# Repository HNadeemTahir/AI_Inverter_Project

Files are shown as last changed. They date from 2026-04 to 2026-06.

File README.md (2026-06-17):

# Solar Inverter & MPPT Booster — Simulation to Hardware

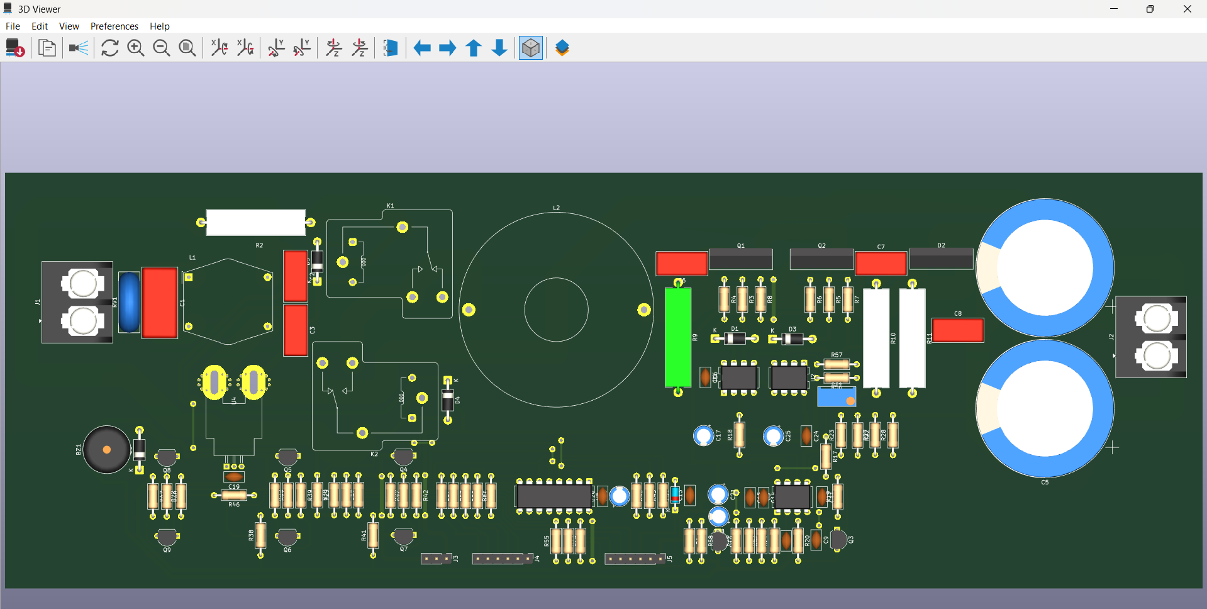
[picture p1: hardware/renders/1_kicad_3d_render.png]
4kW MPPT Booster PCB — KiCad 3D Render


NgSpice simulation and KiCad PCB design of a complete off-grid solar power system. The simulation uses manufacturer SPICE models (not ideal switches) and translates dsPIC30F2010 firmware logic into behavioral equations so the control loops can be validated before building hardware.

Two power conversion stages, developed across 10 versions:

1. **H-Bridge Inverter** — Single-phase 220V/50Hz pure sine wave output using FGY75T120SWD IGBTs, unipolar SPWM, closed-loop PI voltage regulation, electro-thermal monitoring, and hardware fault protection.
2. **4kW MPPT Boost Converter** — DC-DC front-end regulating a variable 120V–350V PV string to a stable 380V DC bus, controlled by a UC3843 analog controller slaved to a dsPIC30F2010 MCU.

---

## Note on Methodology

The workflow here — simulate with real device models, sweep parameters with Python, train a surrogate model, then route the PCB — is not specific to boost converters. The same approach works for any power stage where you need to predict switching losses and thermal behavior before committing to hardware. I have used variations of this on inverter gate drives, motor current loops, and industrial servo tuning.

---

## Project Phases at a Glance

| Version  | Focus Area | Key Achievement |
|:---:|:---|:---|
| V1.0 | Environment Setup | NgSpice + library structure established |
| V2.0 | Half-Bridge SPWM | Ideal switching, basic sine generation |
| V3.0 | Physical IGBT Models | Real FGY75T120SWD switching behavior |
| V4.0 | Full H-Bridge + LC | Unipolar SPWM, motor load, phase lag verified |
| V5.0 | Closed-Loop PI Control | ZMPT101B sensor delay, voltage regulation |
| V6.1 | Dead-Time + Thermal | 2µs shoot-through protection, Foster RC model |
| V6.3 | Python Automation | Batch simulation, CSV data extraction |
| V6.5 | Modulation Benchmark | THI + Dead-Time compensation matrix |
| V7.0 | Surrogate Model | Scikit-Learn Random Forest predictor |
| V8.0 | 4kW MPPT Converter | Feed-forward + PI boost, 3 test profiles |
| V9.0 | UC3843 Control Loop | Analog-digital MPPT integration, gate physics |
| **V10.0**| **Hardware PCB** | **KiCad layout, DRC-clean, 3D-verified** |

---

## Hardware Implementation (KiCad)

The 4kW MPPT booster control board, designed in KiCad 9.0. DRC-clean. The schematic and layout match the UC3843 + dsPIC control architecture from V8.0 and V9.0 simulations.

### PCB 3D Render — Component Side
PCB Top View

### PCB 3D Render — Isometric View
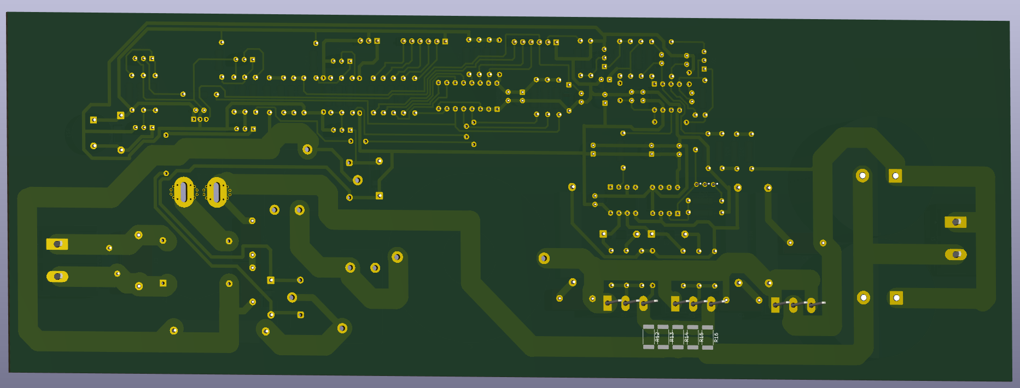
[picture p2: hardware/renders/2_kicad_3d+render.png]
PCB Isometric


### Hardware Design Files

| File | Description |
|:-----|:---|
| [`MPPT_Booster_4kW_Hardware.kicad_pro`](hardware/kicad/MPPT_Booster_4kW_Hardware.kicad_pro) | KiCad 9.0 project file |
| [`MPPT_Booster_4kW_Hardware.kicad_sch`](hardware/kicad/MPPT_Booster_4kW_Hardware.kicad_sch) | Full schematic (UC3843 + dsPIC + gate drivers + current sensing) |
| [`MPPT_Booster_4kW_Hardware.kicad_pcb`](hardware/kicad/MPPT_Booster_4kW_Hardware.kicad_pcb) | PCB layout with copper pours, clearance rules, and thermal relief |
| [`DRC.rpt`](hardware/kicad/DRC.rpt) | Design Rule Check report |

### Key Layout Decisions

- **High-current paths** (inductor → IGBT → diode → output caps) use wide copper pours with thermal relief pads to handle 20A+ continuous current
- **Gate driver isolation** — FOD3150 optoisolators provide galvanic separation between the dsPIC logic ground and the power stage ground
- **Current sensing** — INA181A2 shunt amplifier placed directly adjacent to the sense resistor to minimize noise pickup
- **Analog control section** — UC3843, slope compensation network, and RC timing components grouped together with short trace runs

---

## Version 9.0 — UC3843 Analog Control Loop Integration

This version implements the hardware-level control architecture of the 4kW MPPT booster. It moves beyond behavioral SPICE switches into a real analog control loop where a **UC3843 peak-current-mode PWM controller** is directly slaved to the **dsPIC30F2010** MCU via a KCL-balanced voltage summing node.

### Engineering Targets Achieved

| Target | Method | Status |
|:---|:---|:---:|
| Analog-digital MPPT interface | KCL summing node on UC3843 Pin 2 | ✅ Proven  |
| Cold-boot explosion prevention | 10kΩ pull-up on dsPIC OC1 PWM line | ✅ Proven  |
| Precharge relay MCU isolation | 2N2222 NPN driving 40A contactor coil | ✅ Proven  |
| Sub-harmonic oscillation fix | 2N3904 NPN emitter-follower slope compensation | ✅ Proven  |
| 100ns turn-on noise rejection | 1kΩ + 470pF LEB filter on UC3843 Pin 3 | ✅ Proven  |
| IGBT Miller plateau characterization | Asymmetric gate drive: 15Ω ON / 5.6Ω+D OFF | ✅ Proven  |
| dsPIC PWM-to-analog conversion | 10kΩ + 4.7µF RC filter: 3.3Hz cutoff | ✅ Proven  |

### Test 1 — MPPT Summing Node: dsPIC Duty Cycle Sweep
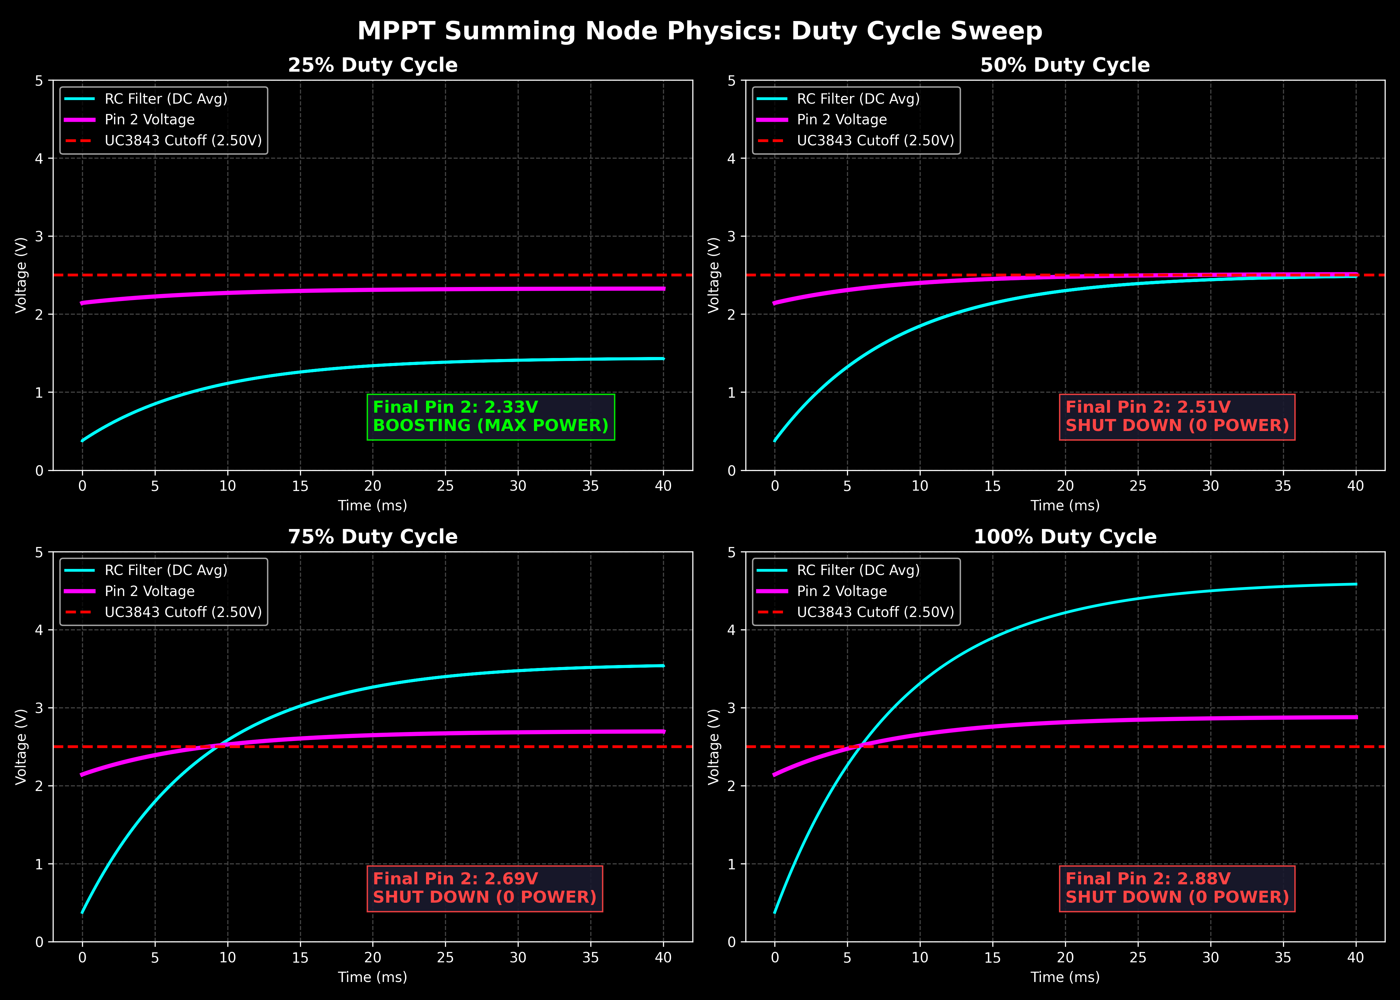
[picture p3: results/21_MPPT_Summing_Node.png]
Summing Node Sweep


Four-point parametric sweep of the dsPIC OC1 PWM duty cycle. Proves the KCL summing node physics: at 25% duty cycle, Pin 2 settles below 2.50V and the UC3843 boosts at maximum power. At 50%–100%, Pin 2 rises above the 2.50V threshold and the converter shuts down in a controlled manner. The 10kΩ pull-up resistor ensures this safe state is the default during MCU boot.

| dsPIC PWM | RC Filter Output | Pin 2 Voltage | UC3843 State |
|:---:|:---:|:---:|:---|
| 25% | 1.25V | 2.33V | Boosting (MAX POWER) |
| 50% | 2.50V | 2.51V | Shut Down |
| 75% | 3.75V | 2.69V | Shut Down |
| 100% | 5.00V | 2.88V | Shut Down |

### Test 2 — Gate Capacitance Charge/Discharge Analysis
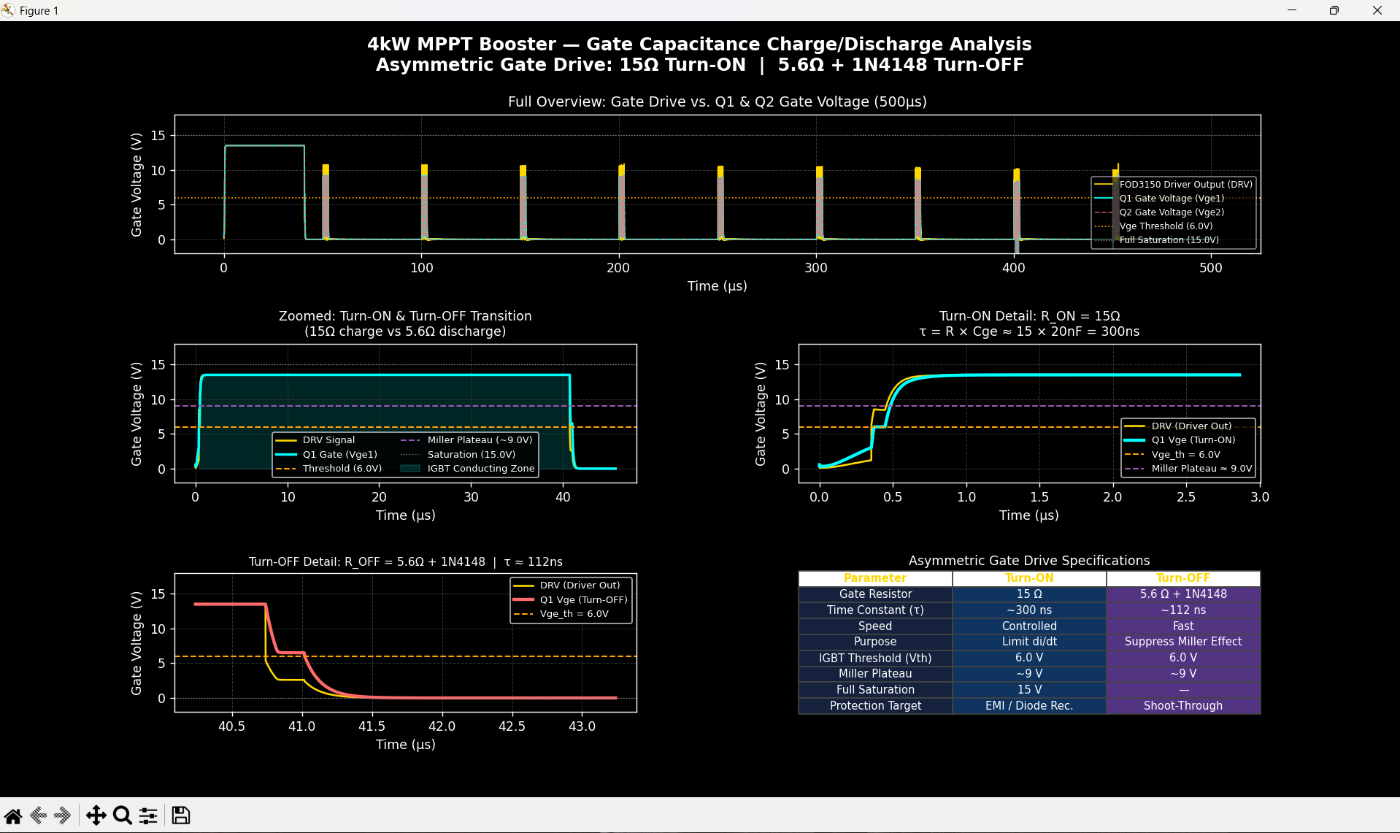
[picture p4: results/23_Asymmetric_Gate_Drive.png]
Gate Analysis Dashboard


500µs high-resolution transient analysis of the asymmetric gate drive network on the STGW60H65DFB parallel IGBT pair. Characterizes the Miller Plateau crossing, threshold voltage events, and the turn-on/turn-off time constants resulting from the 15Ω / 5.6Ω+1N4148 resistor-diode network.

| Parameter | Turn-ON | Turn-OFF |
|:---|:---:|:---:|
| Gate Resistor | 15 Ω | 5.6 Ω + 1N4148 |
| Time Constant (τ) | ~300 ns | ~112 ns |
| Purpose | di/dt limiting, diode recovery ctrl  | Miller effect suppression, shoot-through prevention |
| IGBT Threshold (Vth) | 6.0 V | 6.0 V |
| Miller Plateau | ~9 V | ~9 V |
| Full Saturation | 15 V | — |

### Test 3 — UC3843 Closed-Loop Boost Converter
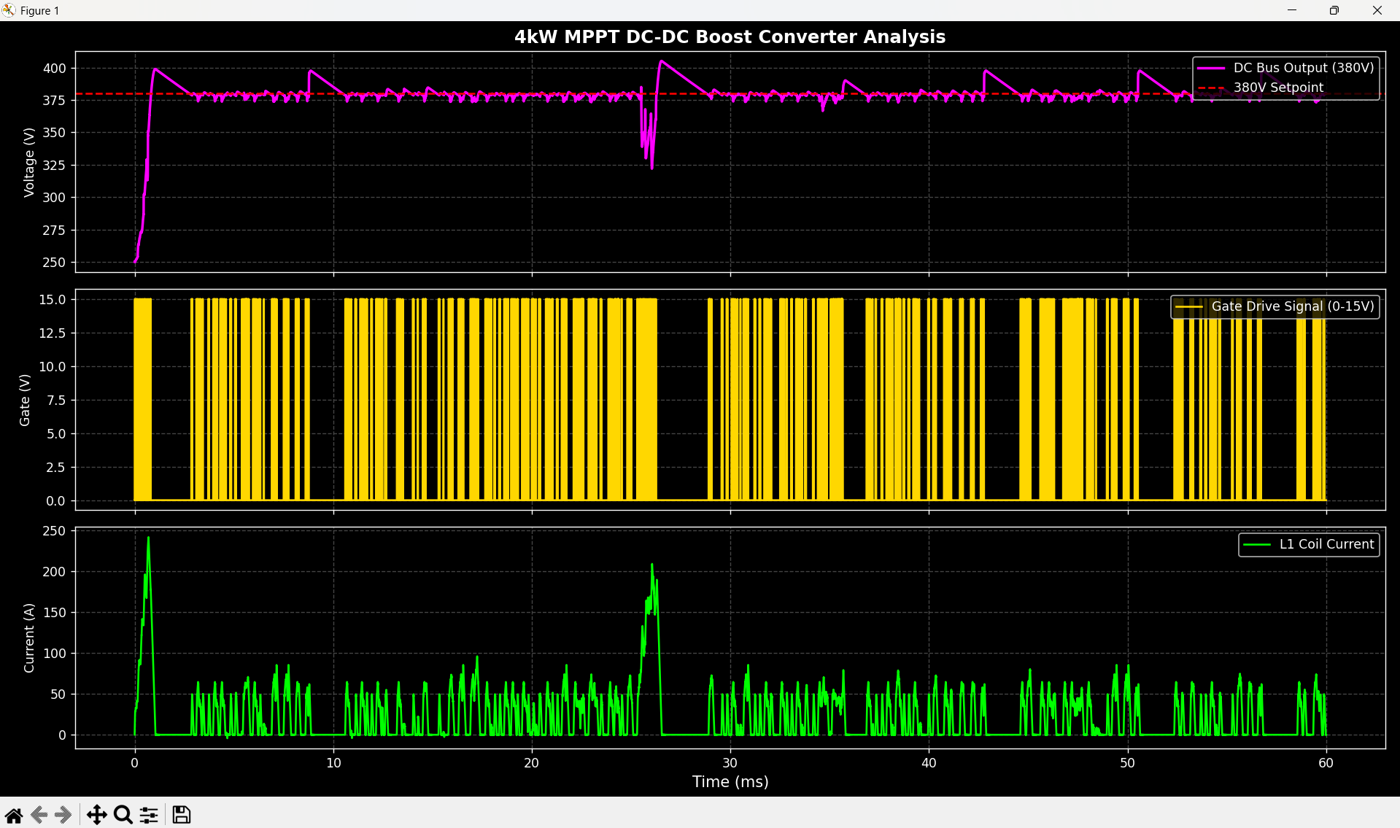
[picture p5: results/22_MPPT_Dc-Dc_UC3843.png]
MPPT UC3843 Dashboard


Full closed-loop simulation of the UC3843 controlling the power stage. Shows the DC bus regulation, inductor current waveform, and the 20kHz gate drive signal across the full 60ms transient window.

### Test 4 — LEB Filter: 470ns Current Sense Propagation Delay
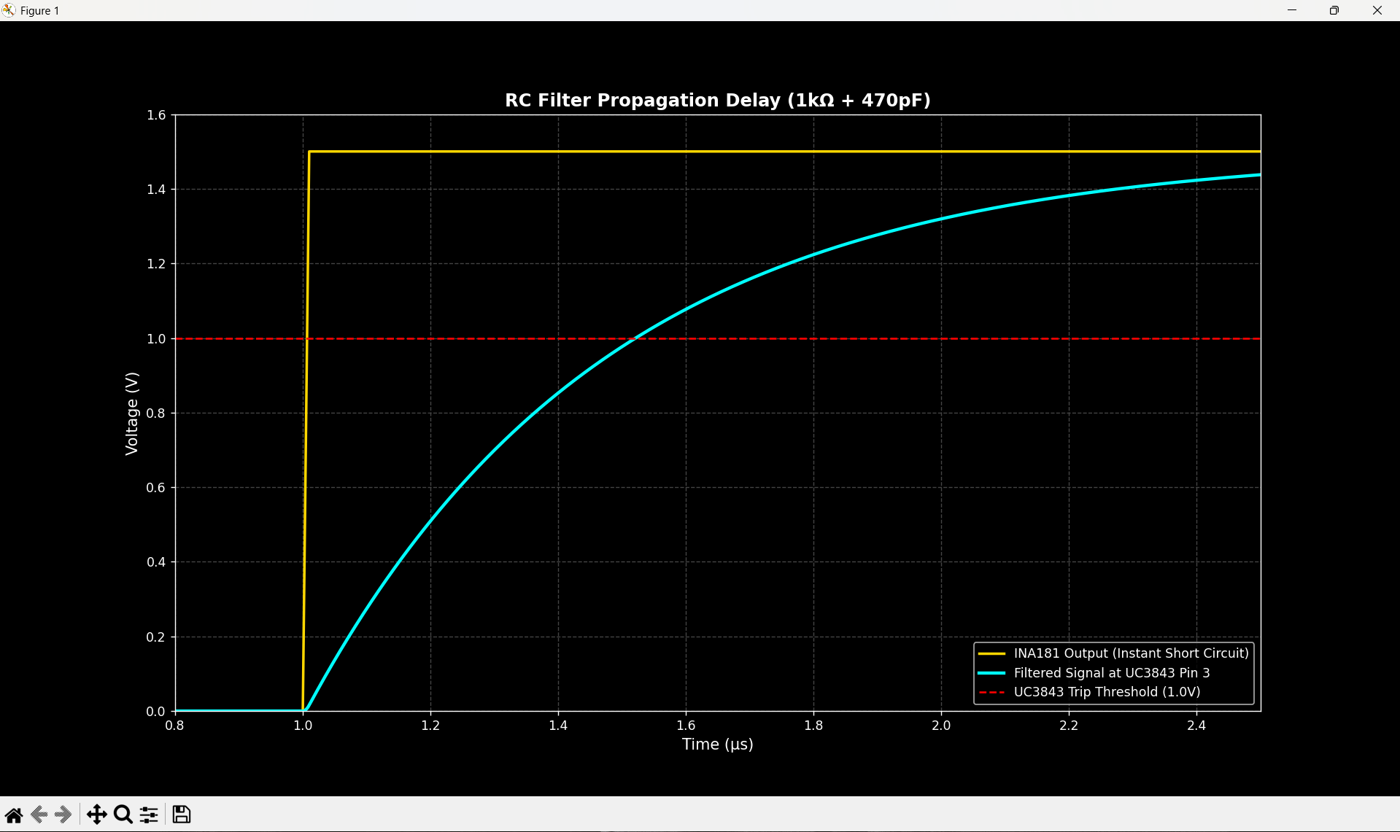
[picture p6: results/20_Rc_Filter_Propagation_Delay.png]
RC Filter Delay


Step-response analysis of the Leading Edge Blanking (LEB) filter at UC3843 Pin 3. A simulated dead-short event causes the INA181 output to jump instantaneously to 1.5V. The 1kΩ + 470pF RC filter delays the signal reaching the 1.0V trip threshold by 470ns — exactly the blanking window required to mask IGBT turn-on current spikes while remaining fast enough to detect a genuine short circuit within one switching cycle.

---

## Version 8.0 — 4kW MPPT Boost Converter

Full power-stage simulation of the 4kW DC-DC booster. Feed-forward + PI control architecture handles 3-panel to 8-panel PV string inputs.

### Booster Specifications

| Parameter | Value |
|:---|:---|
| Input Range | 120V – 350V DC |
| Output | 380V DC (regulated) |
| Max Power | 4000W |
| Switching Frequency | 20kHz |
| IGBTs | 2× STGW60H65DFB (650V/60A, parallel) |
| Boost Diode | STTH3006D (600V/30A, 35ns Trr) |
| Gate Driver | FOD3150 (optically isolated) |
| Control | Feed-Forward + PI with anti-windup |

### Validated Test Profiles

| Profile | Input | Load  | Steady State | Verdict  |
|:---|:-----:|:-----:|:---:|:---:|
| 3-Panel String | 120V  | 1500W | 380V flat | **PASS** |
| 5-Panel String | 250V  | 3000W | 380V flat | **PASS** |
| 8-Panel String | 350V  | 4000W | 380V ±10V† | **PASS** |

† Bounded oscillation at 350V is LC resonance at near-unity boost ratio. Eliminated in firmware by a single-coefficient EMA filter: `vbus_filt = 0.015 * raw + 0.985 * filt`.

### Profile 1: 120V → 380V (1500W, Boost Ratio 3.17×)
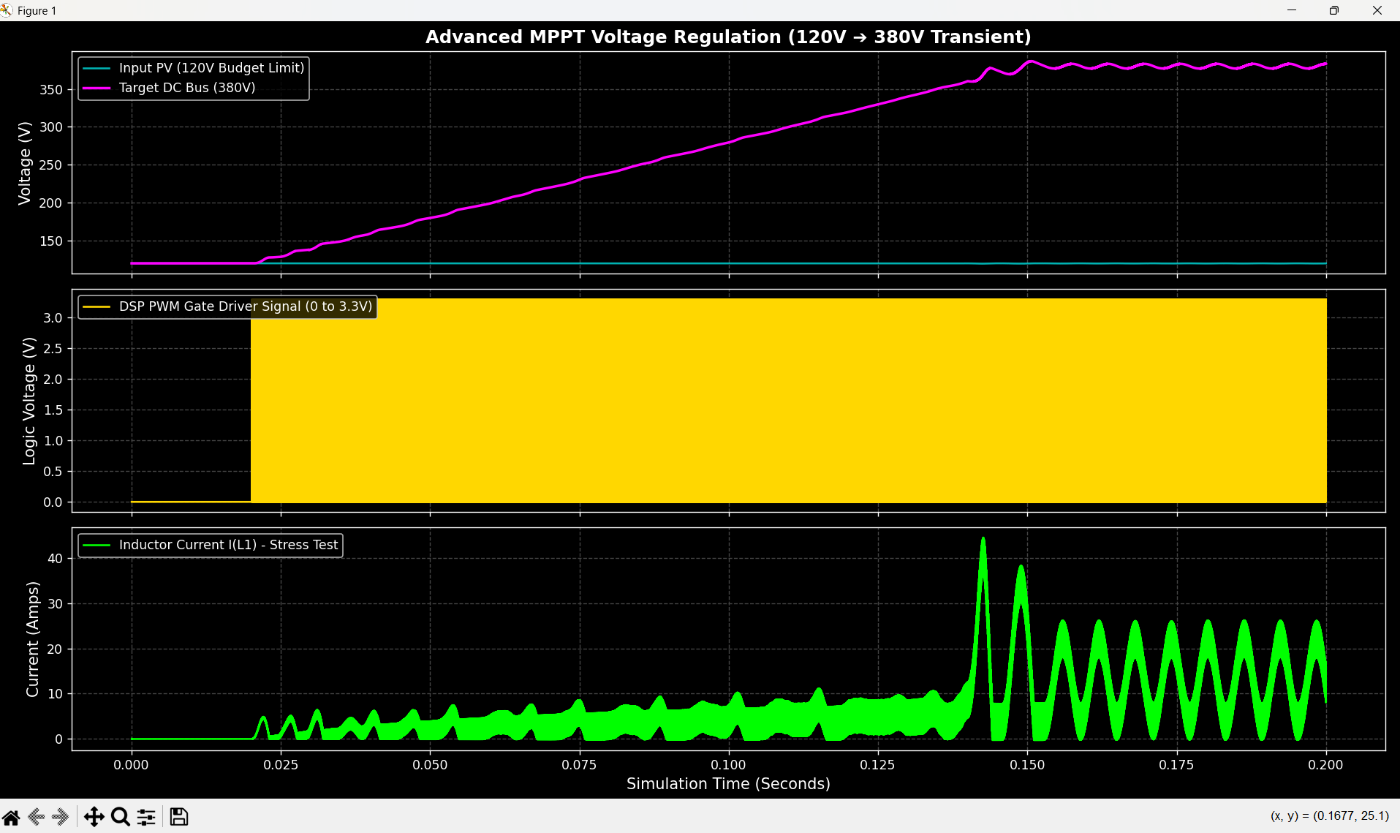
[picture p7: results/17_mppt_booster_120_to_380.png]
MPPT 120V


### Profile 2: 250V → 380V (3000W, Boost Ratio 1.52×)
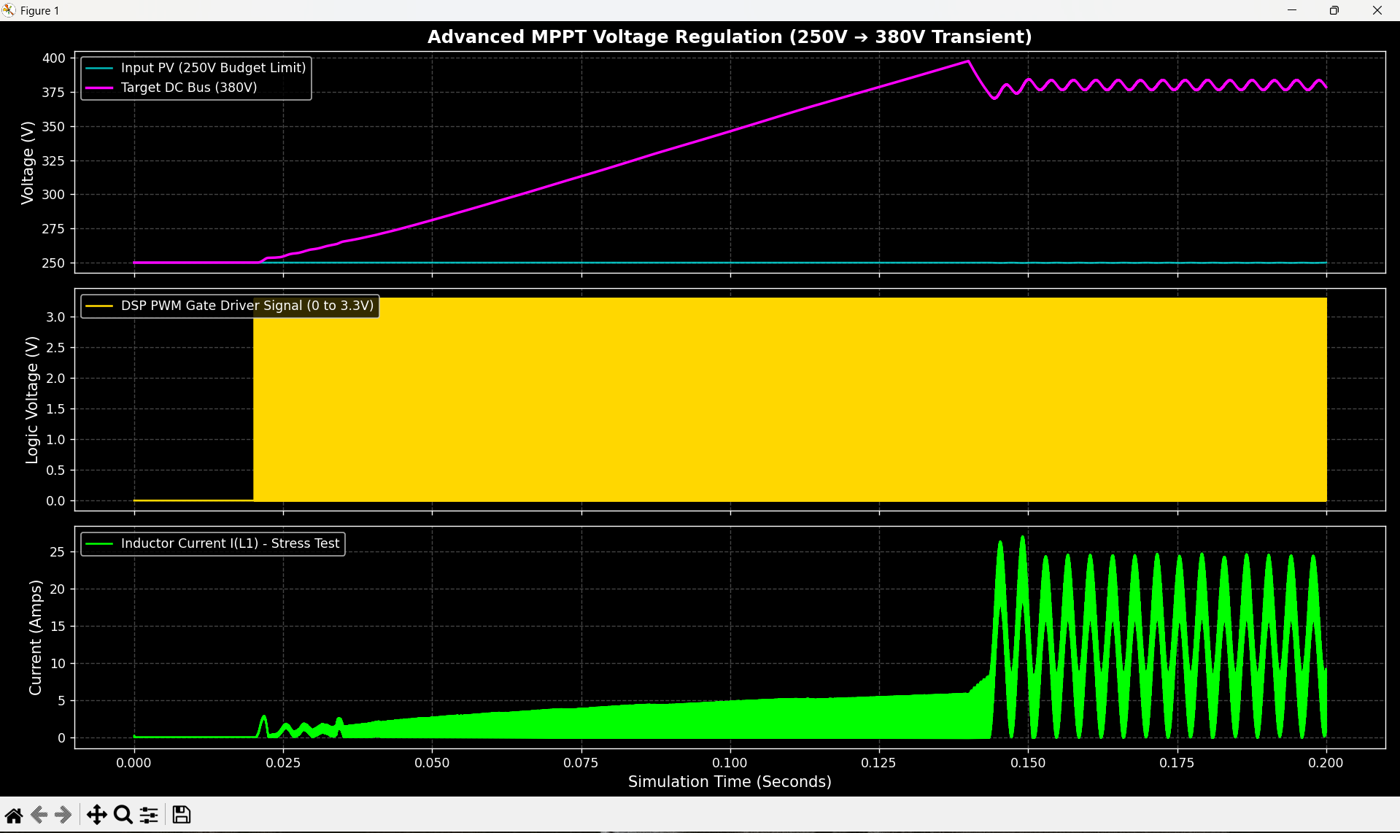
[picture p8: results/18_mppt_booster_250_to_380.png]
MPPT 250V


### Profile 3: 350V → 380V (4000W, Boost Ratio 1.09×)
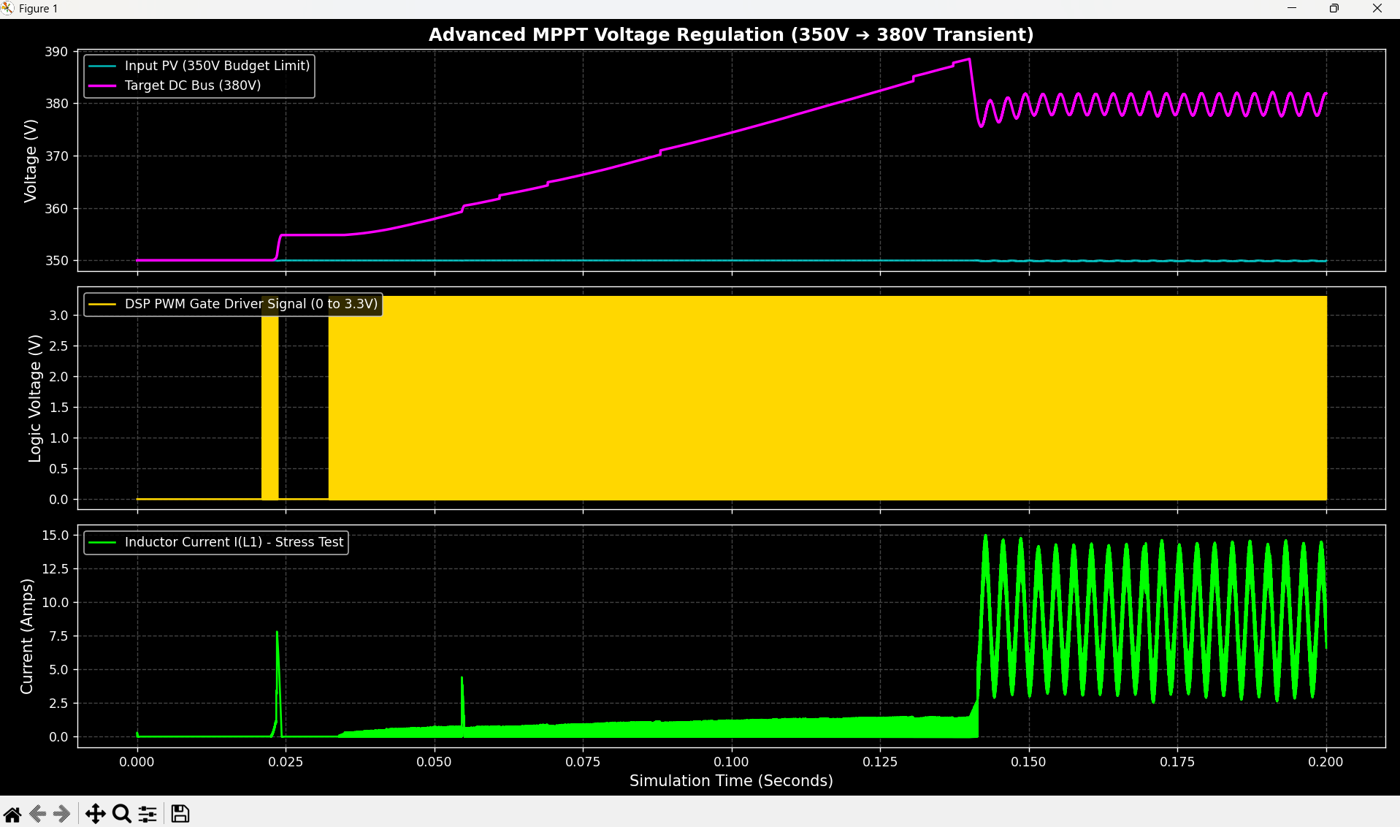
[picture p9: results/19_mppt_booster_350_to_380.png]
MPPT 350V


### Critical Design Findings
- **Feed-forward is mandatory** at high boost ratios. Without it, the PI controller cannot reach 68% duty cycle fast enough, producing 250A+ inductor current spikes on startup.
- **Load connection sequence matters** — connecting the inverter load before the DC bus reaches 90% of target produces 400A+ surge currents due to the discharged output capacitor acting as a short circuit.
- **Firmware EMA filter required** at 350V operating point to damp the LC resonance visible in the 350V simulation profile.

---

## Version 7.0 — Surrogate Model (Scikit-Learn)

A Random Forest Regression model trained on 204 NgSpice simulations generated by the parametric data factory. The predictor approximates IGBT junction temperature, efficiency, and AC output voltage for any input condition in under 0.01 seconds — eliminating the need to run a full transient simulation during firmware tuning.

### Surrogate Model Accuracy
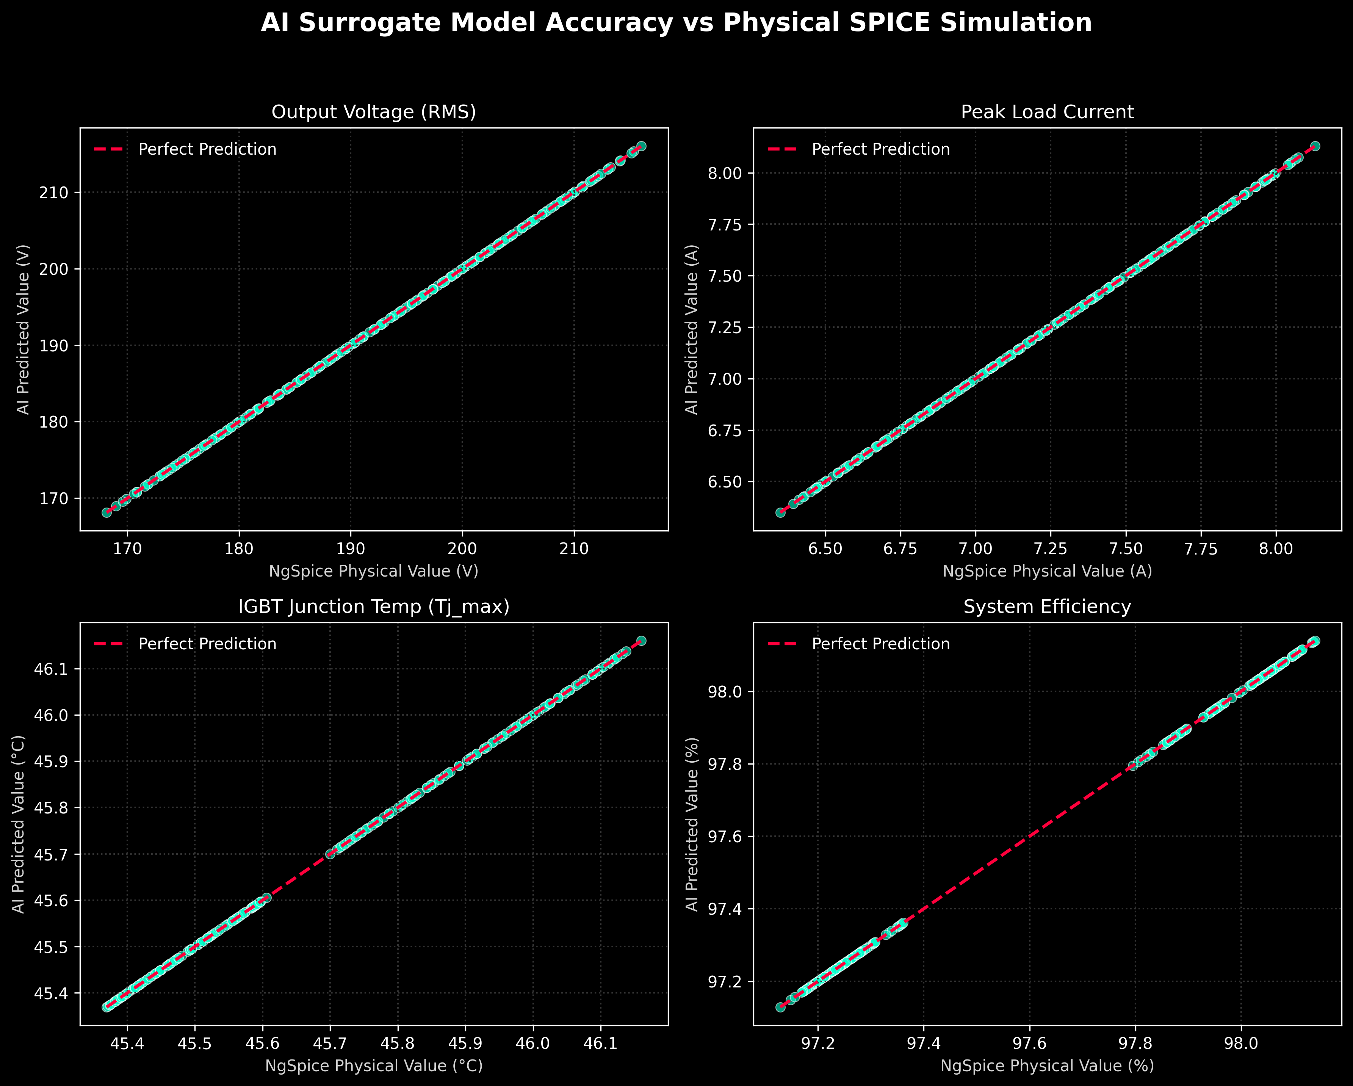
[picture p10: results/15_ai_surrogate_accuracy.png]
Surrogate Accuracy


### Instant Performance Predictor
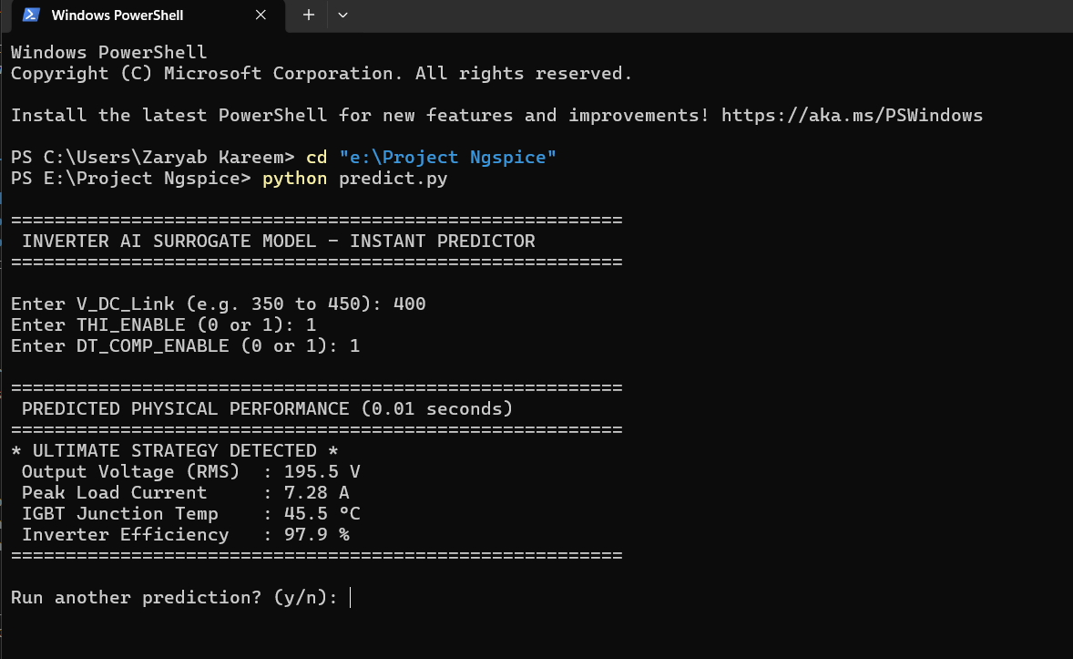
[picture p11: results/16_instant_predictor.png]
Predictor Interface


---

## Version 6.5 — Modulation Strategy Benchmark

Four independently toggled modulation strategies benchmarked against each other using a parametric sweep across 400V DC link conditions.

### Strategy Matrix

| THI | DT Comp | Strategy | V_rms | Tj_max | Efficiency |
|:---:|:---:|:---|:---:|:---:|:---:|
| OFF | OFF | Bare SPWM | 188.7V | 45.9°C | 97.2% |
| OFF | ON | SPWM + DT Comp  | 192.1V | 45.5°C | 98.1% |
| ON  | OFF | THI Flat-Top | 192.8V | 45.9°C | 97.2% |
| ON  | ON | THI + DT Comp | **195.5V** | **45.5°C** | 97.9% |

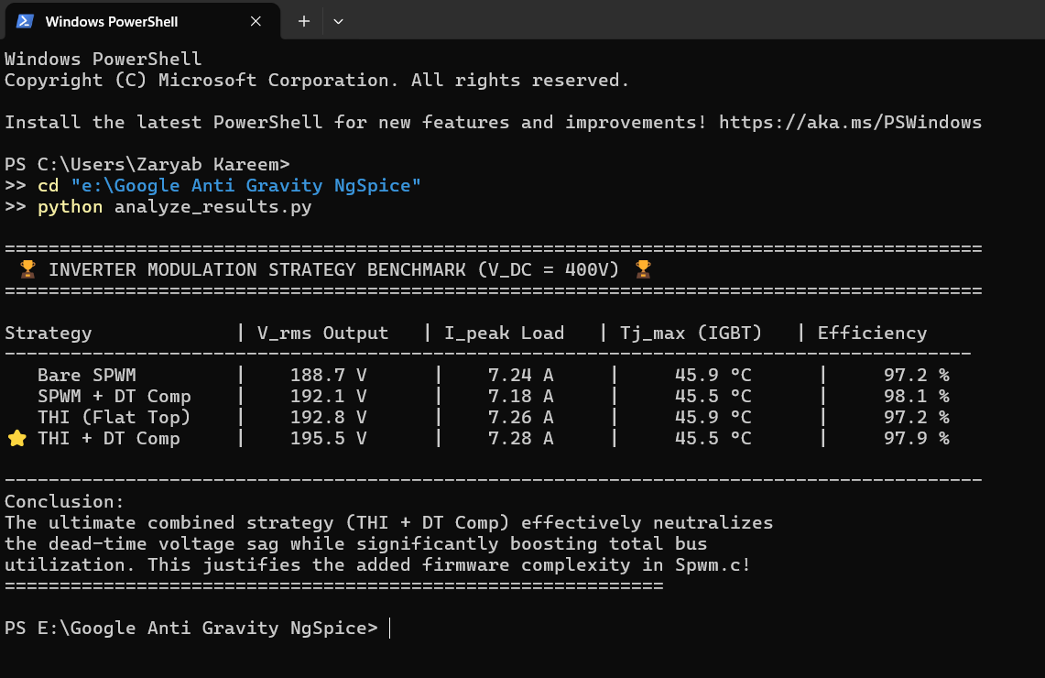
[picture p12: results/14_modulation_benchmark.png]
Modulation Benchmark


The combined strategy recovers 6.8V of AC output. Uncompensated dead-time introduces harmonic distortion that recirculates as I²R heat — compensating it in firmware improves both output voltage and thermal efficiency simultaneously.

---

## Inverter Simulation Results (V6.5 Reference)

### Output Voltage — Inductive Motor Load
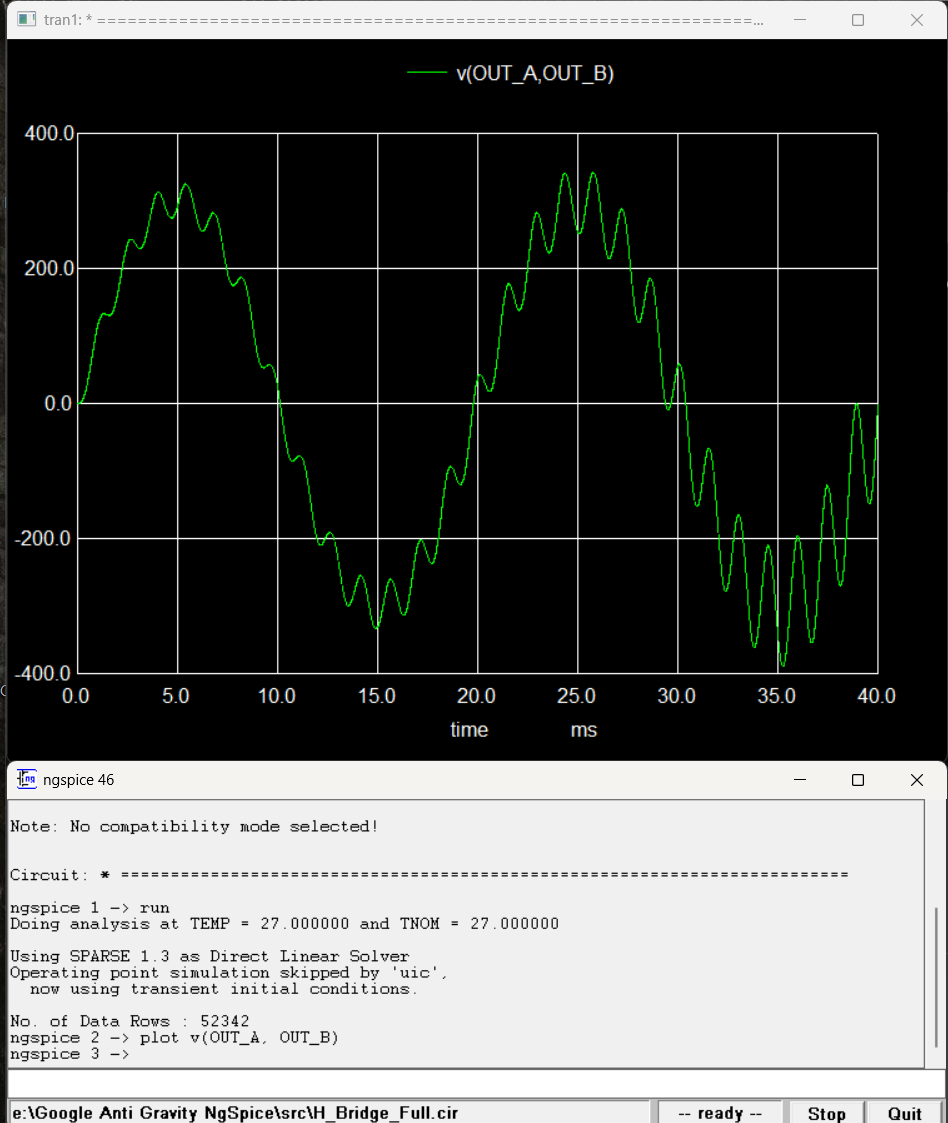
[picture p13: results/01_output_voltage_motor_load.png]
Output Voltage

*50Hz output into 20Ω/100mH R-L load. Peak ±311V.*

### Voltage-Current Phase Lag
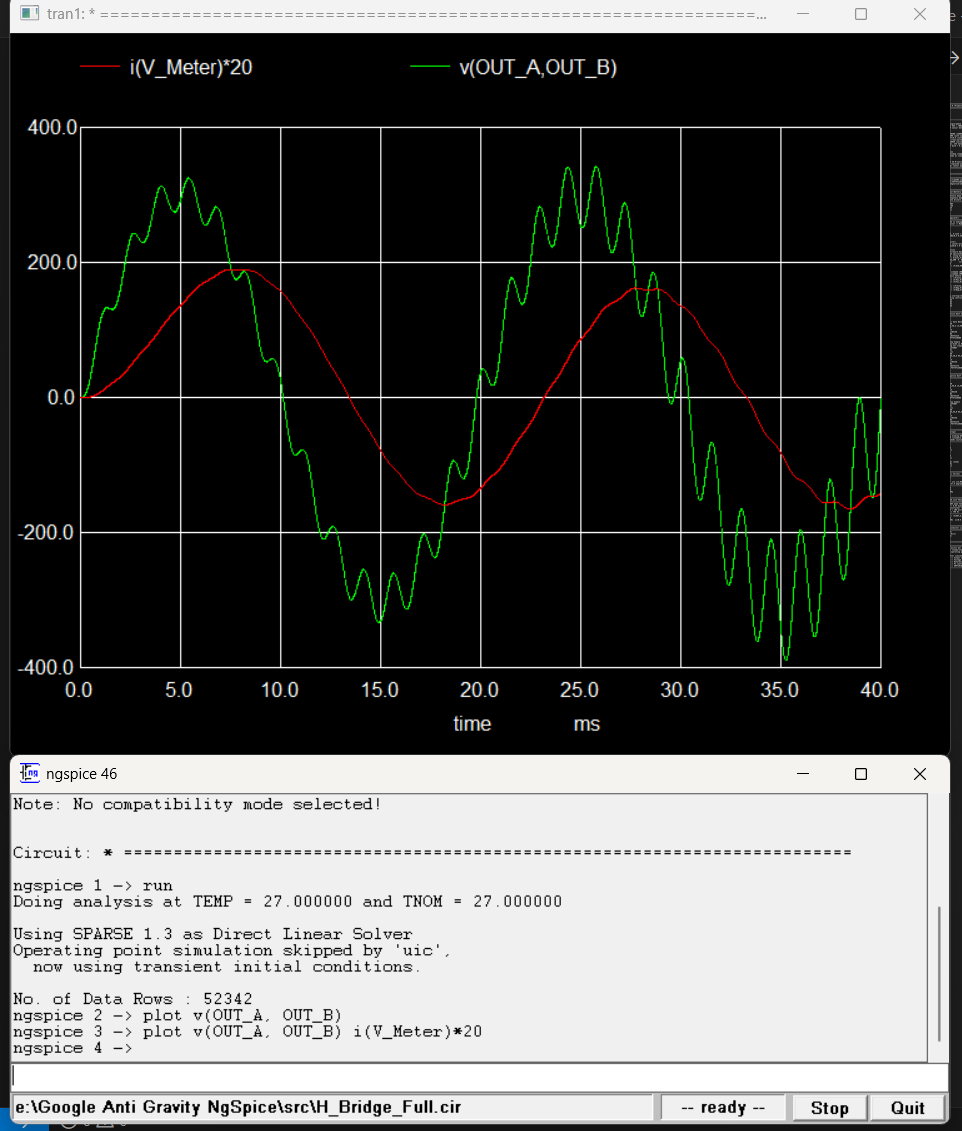
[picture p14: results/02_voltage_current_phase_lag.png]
Phase Lag

*Current lags voltage by ~57°. Confirmed: arctan(2π × 50 × 0.1 / 20) = 57.5°.*

### PI Controller: Reference vs Feedback
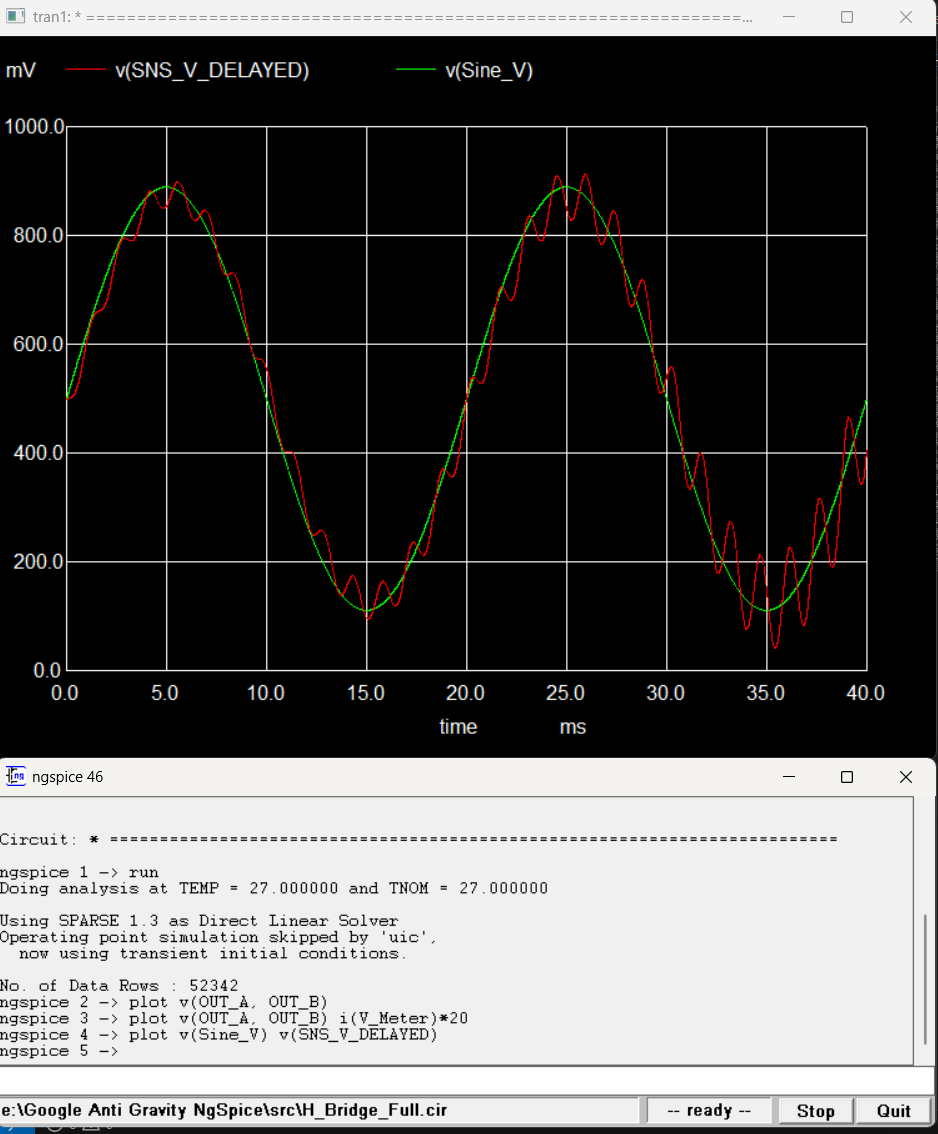
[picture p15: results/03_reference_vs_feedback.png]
PI Reference

*ZMPT101B-delayed feedback vs reference. PI controller achieves tracking within 2 cycles.*

### PI Controller Internal Signals
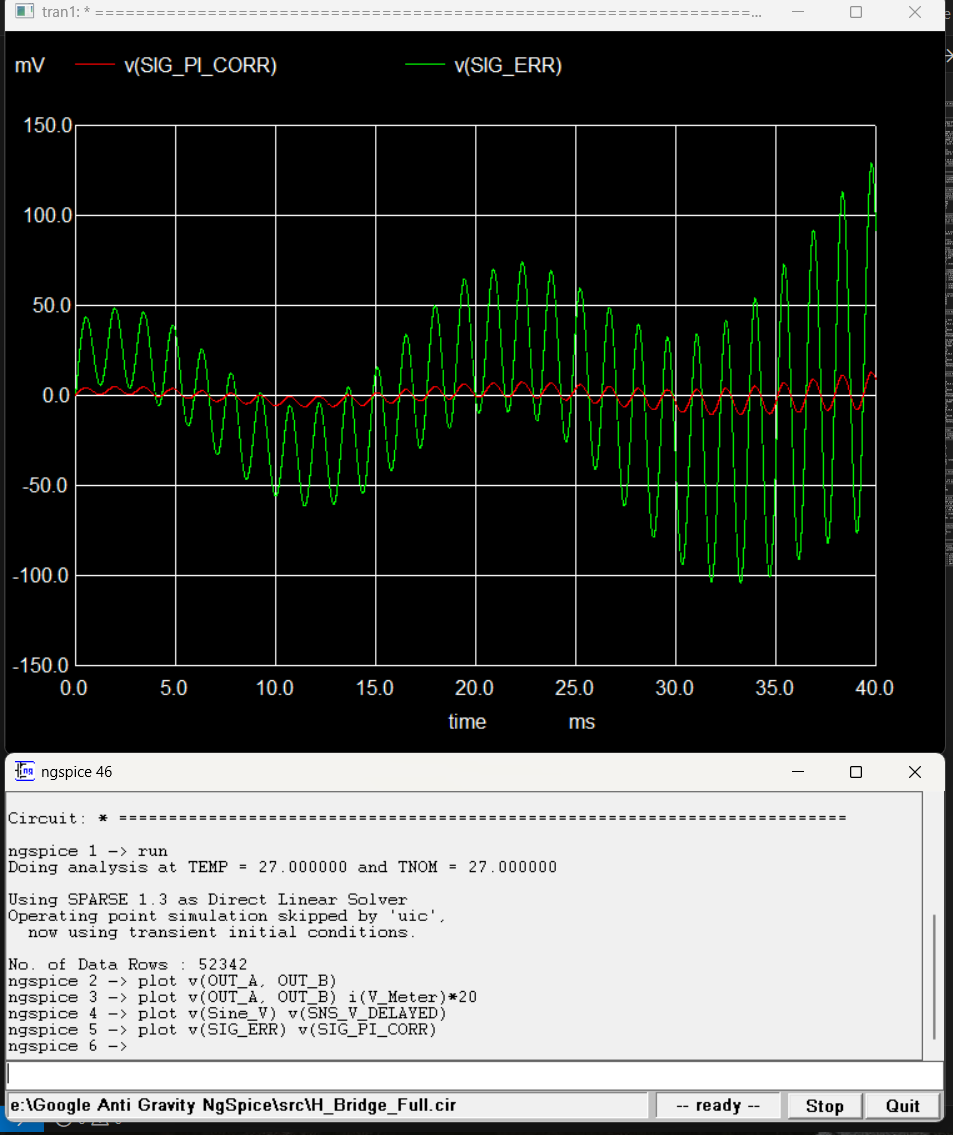
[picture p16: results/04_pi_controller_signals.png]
PI Internals

*Error and integral signals. Integral term stabilizes by 20ms.*

### ZMPT101B Sensor Delay
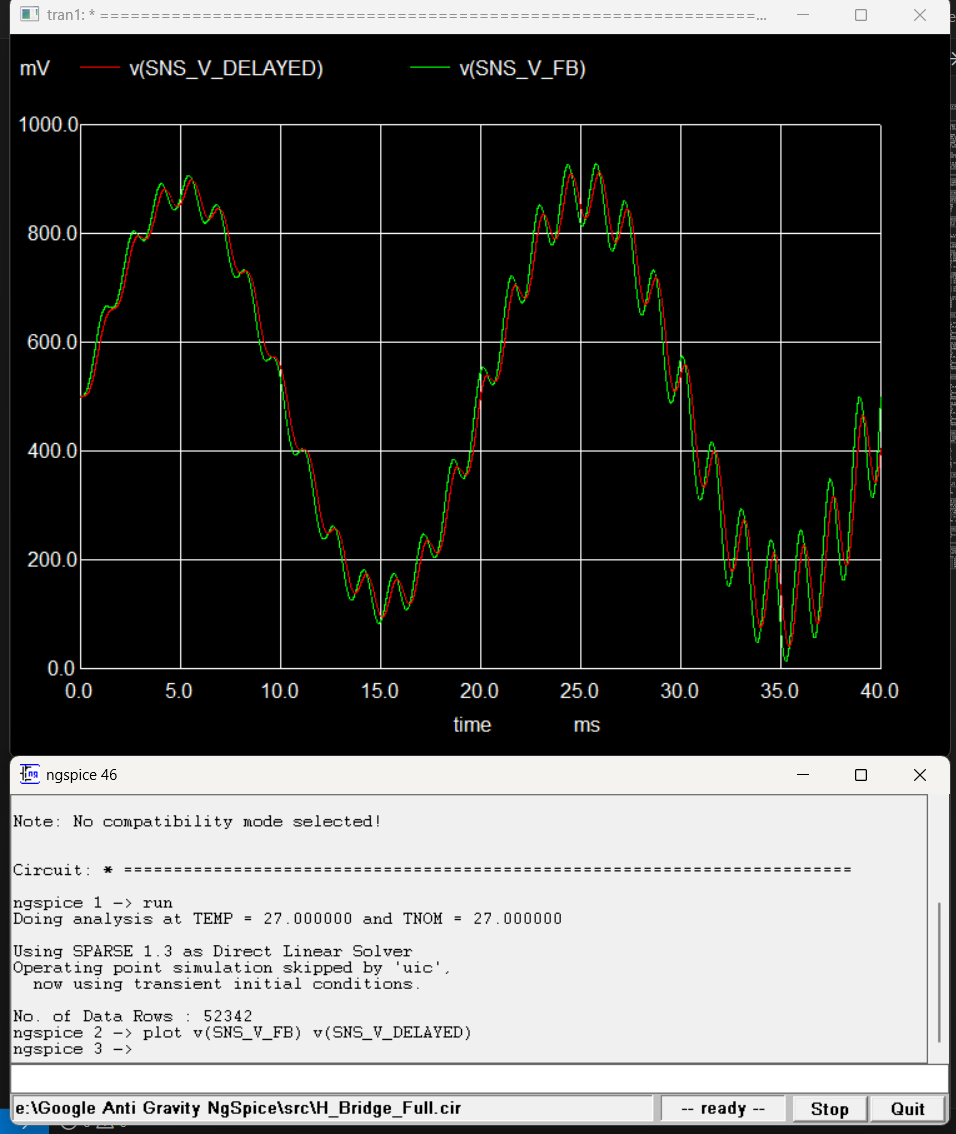
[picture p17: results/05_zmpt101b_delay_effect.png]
ZMPT Delay

*200µs RC group delay (2kΩ / 100nF) modeled from physical transformer + PCB filter.*

### Dead-Time Protection — Gate Signals
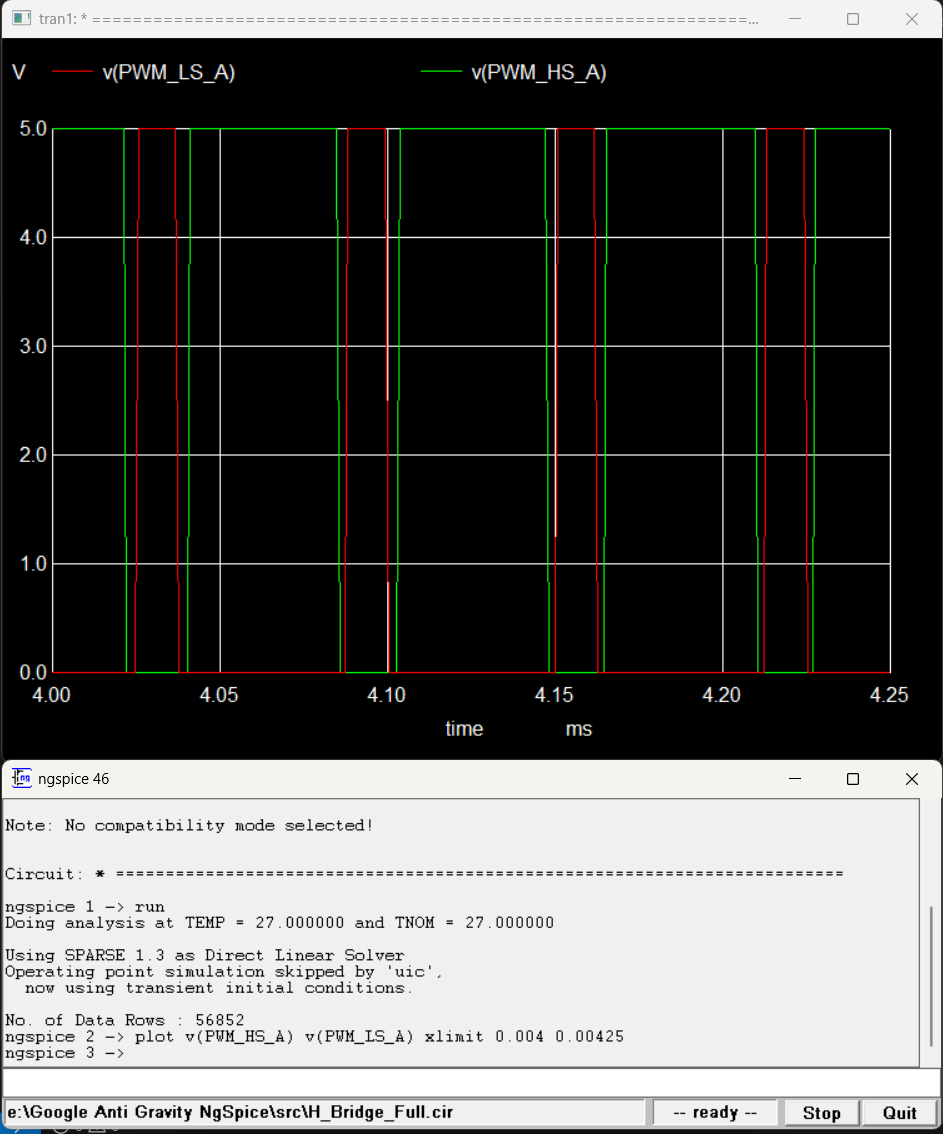
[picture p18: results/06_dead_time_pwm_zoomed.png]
Dead-Time PWM

*~2µs dead-time gap between Leg A HS and LS transitions, matching dsPIC DTCON1 register.*

### DC Bus Energy Flow
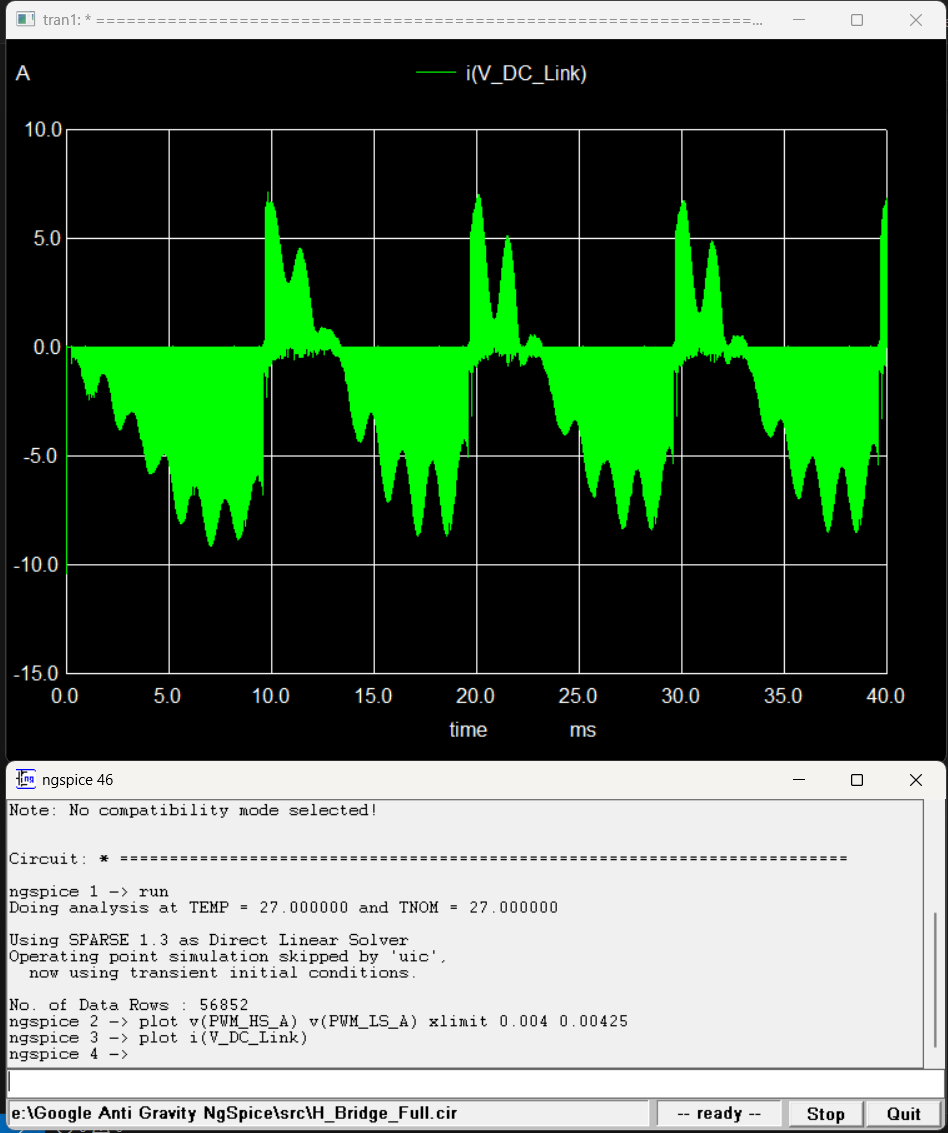
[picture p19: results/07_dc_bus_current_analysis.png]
DC Bus

*Negative current = energy delivery to load. Positive spikes at zero-crossings = inductive freewheeling through body diodes.*

### Short-Circuit Protection (50A Trip)
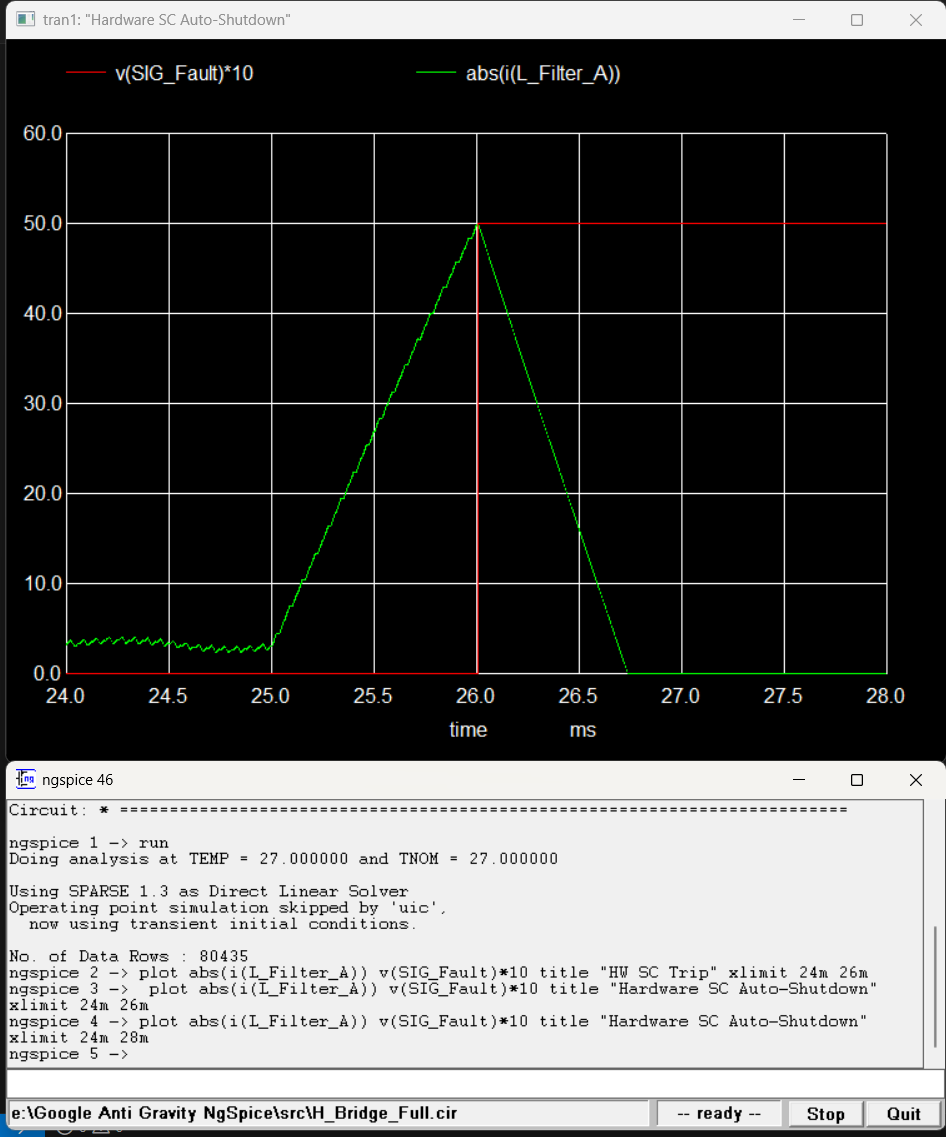
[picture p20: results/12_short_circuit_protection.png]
Short Circuit

*0.1Ω dead-short at t=25ms. CT + comparator trips INT0 latch at 50A primary. Current decays through freewheeling path within 1ms.*

### Electro-Thermal IGBT Junction
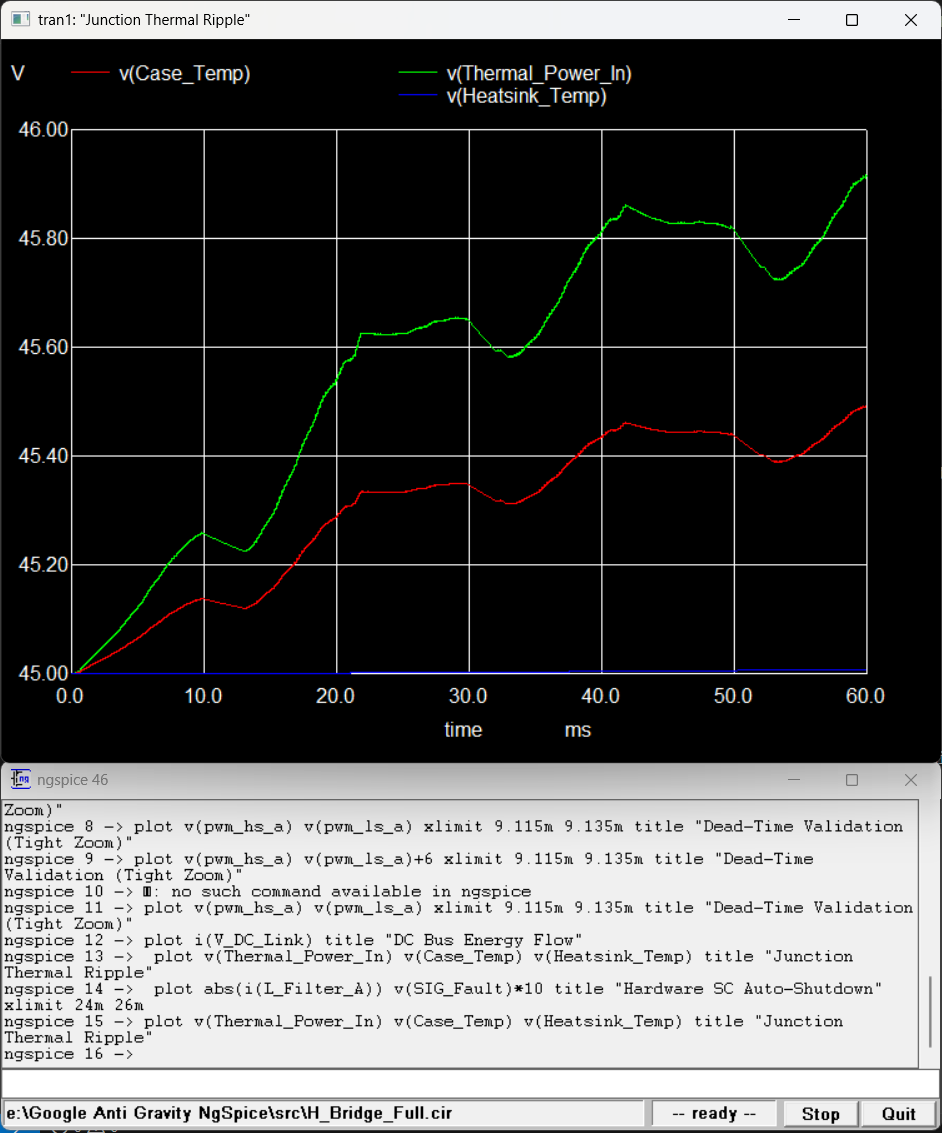
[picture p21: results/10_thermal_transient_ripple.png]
Thermal

*Foster RC network output. 50Hz thermal ripple at junction node. Heatsink stable at 45°C.*

### Dead-Time Validation (Single Event)
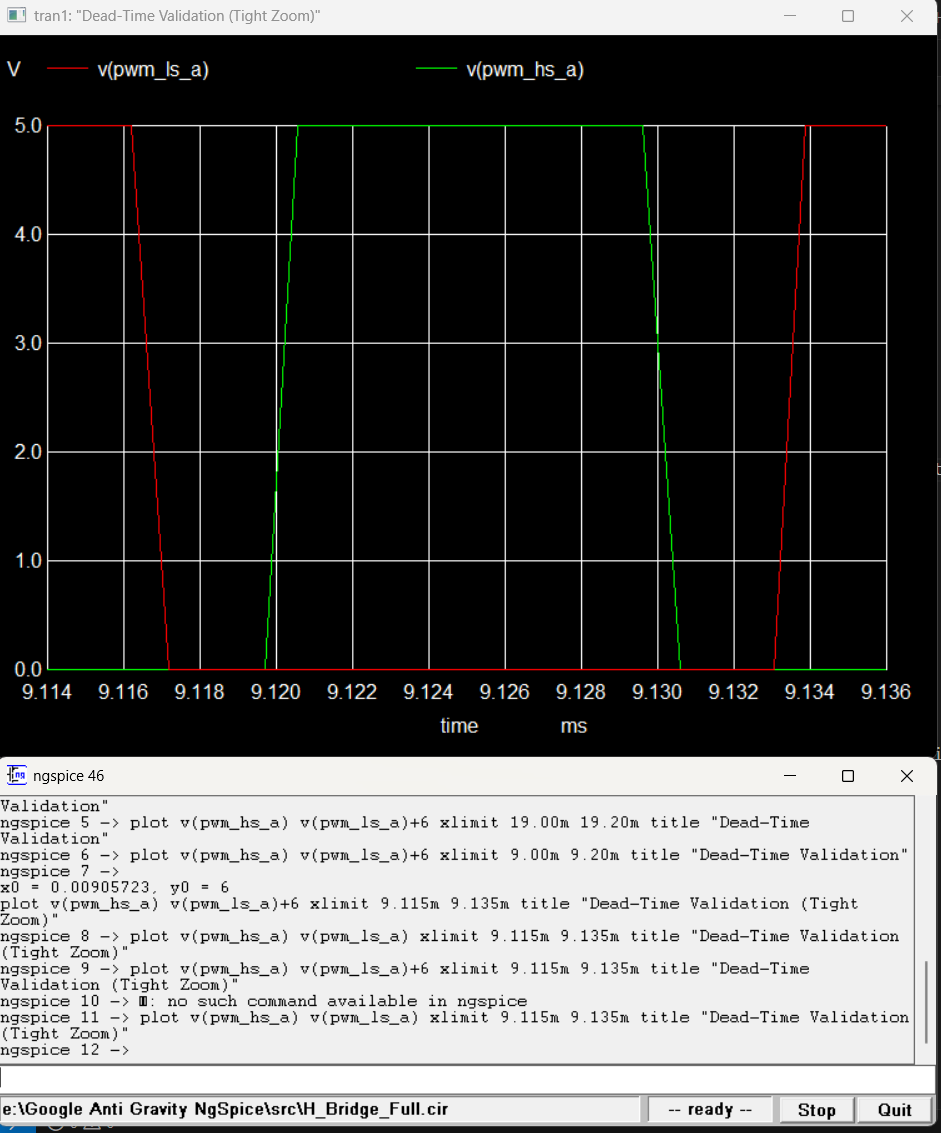
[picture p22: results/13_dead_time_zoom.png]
Dead-Time Zoom

*Single switching event: both gate signals at 0V for the full 2µs dead-time interval.*

### Unipolar SPWM Logic
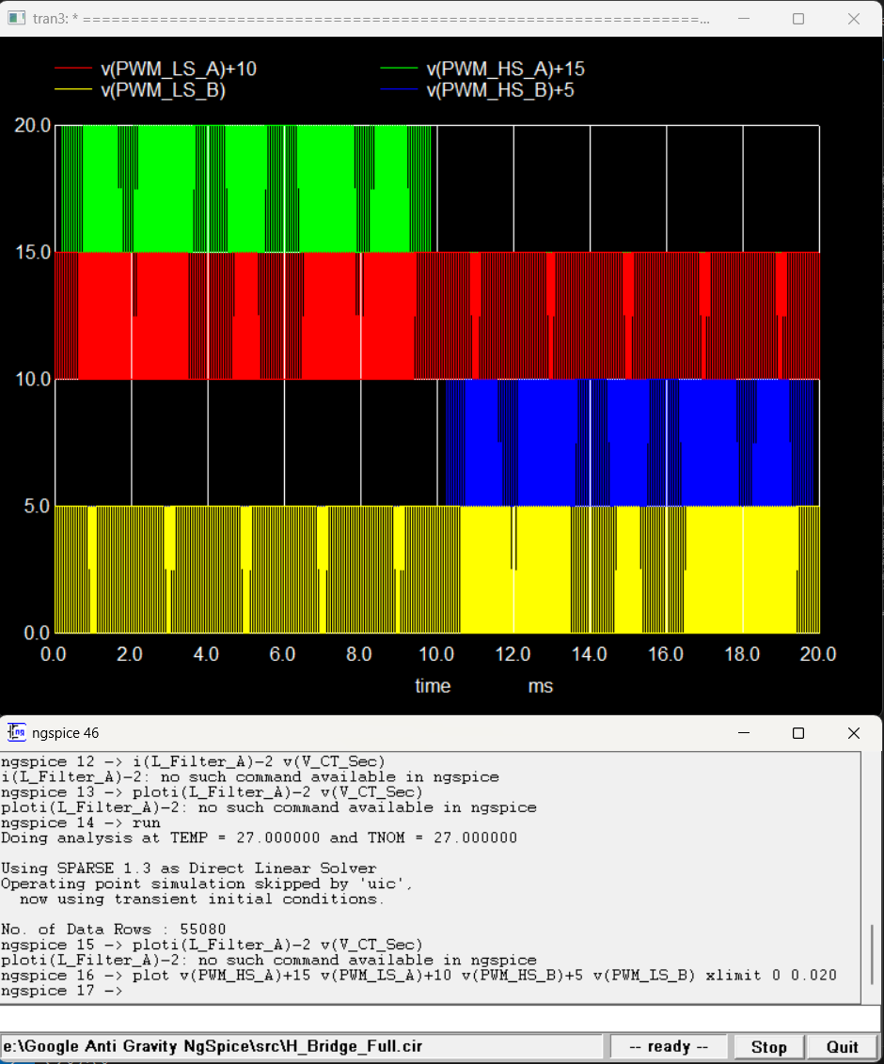
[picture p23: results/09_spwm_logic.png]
SPWM Logic

*Full 20ms cycle. Leg A switches at 16kHz on the positive half; Leg B clamped. Roles exchange at zero-crossing.*

---

## Electro-Thermal IGBT Model

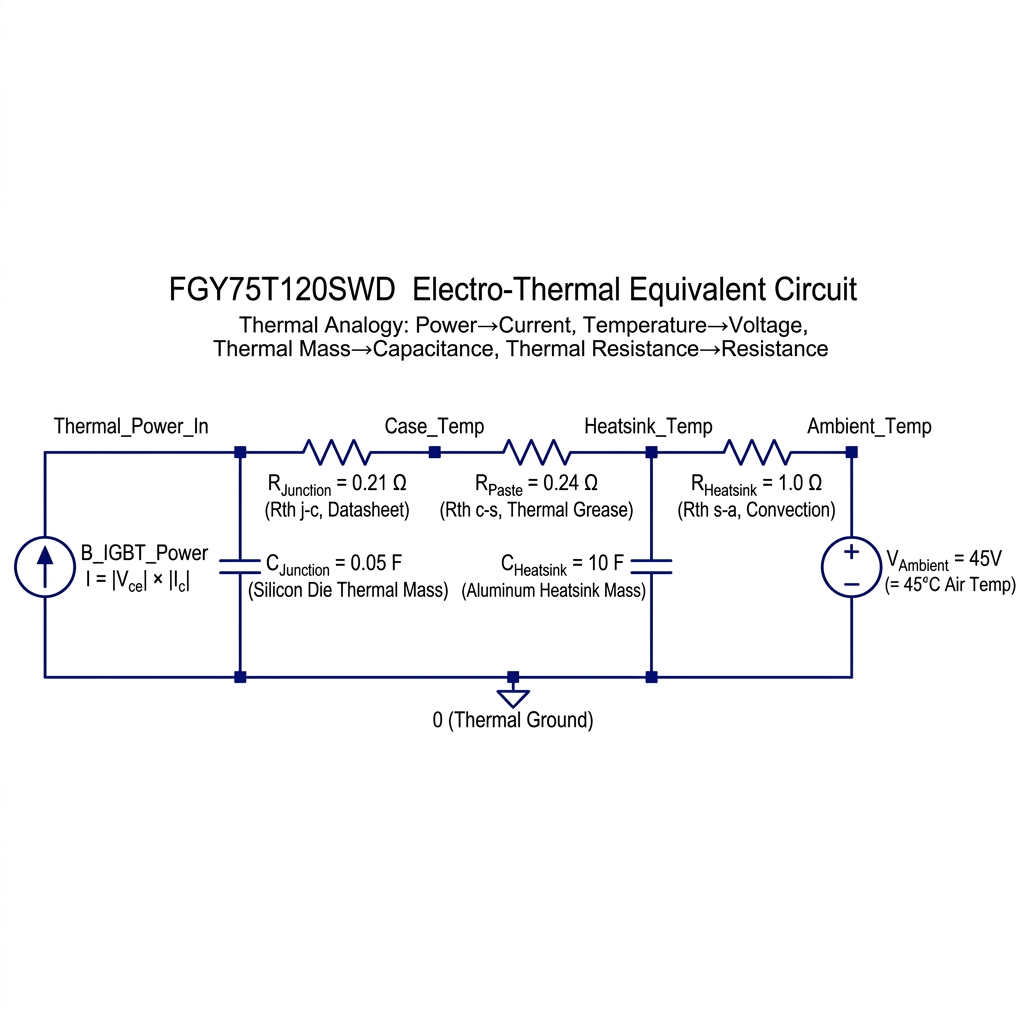
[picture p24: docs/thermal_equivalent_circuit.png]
Thermal Equivalent


Foster RC network mapping power dissipation to junction temperature. Standard power electronics electro-thermal equivalence:

| Thermal Domain | Electrical Equivalent |
|:---|:---|
| Power (W) | Current Source (A) |
| Temperature (°C) | Voltage (V) |
| Thermal Mass (J/°C) | Capacitance (F) |
| Thermal Resistance (°C/W) | Resistance (Ω) |

**Parameters (onsemi FGY75T120SWD datasheet):**

| Stage | Parameter | Value |
|:---|:---|:---|
| Junction to Case | Rth(j-c)  | 0.21 °C/W |
| Junction Thermal Mass | Cth | 0.05 F |
| Case to Heatsink | Rth(c-h)  | 0.24 °C/W |
| Heatsink to Ambient | Rth(h-a)  | 1.0 °C/W |
| Ambient | V_Ambient | 45°C (worst-case)  |

**Steady-state at 40W average dissipation per IGBT:**
> T_junction = 40 × (0.21 + 0.24 + 1.0) + 45 = **103°C** — within the 175°C absolute maximum.

---

## Component Models

### FGY75T120SWD (onsemi, Inverter)
- 1200V / 75A Field Stop VII IGBT
- Models Miller Plateau and switching transitions
- Rth(j-c) = 0.21°C/W, Tj_max = 175°C

### TLP250H (Toshiba, Inverter Gate Driver)
- Custom 8-pin behavioral subcircuit
- 150ns propagation delay, totem-pole output
- Gate protection: 15V Zener, 10kΩ pull-down, bootstrap diode (UF4007)

### ZMPT101B (Voltage Sensor)
- 200µs RC delay model (R=2kΩ, C=100nF)
- Scaling: 311V peak → 0.389V peak + 0.5V bias

### STGW60H65DFB (ST, Booster)
- 650V / 60A Trench Field-Stop IGBT
- Parallel pair: 120A combined continuous rating
- Modeled with Cies, Cres, and integrated body diode

### FOD3150 (Booster Gate Driver)
- Behavioral model: LED threshold sensing, 150ns propagation delay
- Totem-pole output with ±2.5A peak current

### STTH3006D (ST, Boost Diode)
- 600V / 30A ultra-fast recovery diode
- Trr = 35ns — matched for 20kHz freewheeling

### UC3843 Behavioral Model
- Peak-current-mode PWM controller
- 20kHz oscillator: Rt = 8.6kΩ, Ct = 10nF
- Over-current trip at 1.0V on Pin 3 (ISENSE)

---

## Project Structure

```
├── hardware/
│   ├── kicad/                             # KiCad 9.0 project, schematic, and PCB layout
│   │   ├── MPPT_Booster_4kW_Hardware.kicad_pro
│   │   ├── MPPT_Booster_4kW_Hardware.kicad_sch
│   │   ├── MPPT_Booster_4kW_Hardware.kicad_pcb
│   │   └── DRC.rpt
│   └── renders/                           # 3D PCB screenshots
│
├── models/
│   ├── FGY75T120SWD.lib                   # onsemi 1200V/75A IGBT (inverter)
│   ├── tlp250h.sub                        # TLP250H gate driver (inverter)
│   ├── STGW60H65DFB.lib                   # ST 650V/60A IGBT (booster)
│   ├── STTH3006D.lib                      # ST fast-recovery boost diode
│   ├── FOD3150.sub                        # FOD3150 gate driver (booster)
│   └── UC3843_Behavioral.sub              # UC3843 controller model
│
├── src/
│   ├── H_Bridge_Full.cir                  # Inverter master netlist (V6.5)
│   ├── MPPT_Booster.cir                   # Booster — feed-forward PI (V8.0)
│   ├── MPPT_Booster_UC3843.cir            # Booster — UC3843 closed-loop (V9.0)
│   ├── Gate_Analysis.cir                  # Gate RC charge/discharge (V9.0)
│   ├── Summing_Node_Test.cir              # KCL summing node sweep (V9.0)
│   └── RC_Filter_Test.cir                 # LEB 470ns delay test (V9.0)
│
├── docs/
│   ├── MPPT_Booster_Engineering_Report.md
│   ├── MPPT_Booster_BOM_Purchasing_List.md
│   ├── Boost_Inductor_Design_Calculations.md
│   ├── UC3843_Hardware_Design_Guide.md
│   ├── INA181A2_Hardware_Design_Guide.md
│   └── thermal_equivalent_circuit.png
│
├── results/                                # Waveform graphs (numbered by version)
│
├── run_simulation.py                       # Inverter: single-run executor
├── run_mppt_sim.py                         # Booster: 3-profile sweep
├── run_mppt_uc3843.py                      # UC3843 closed-loop booster (V9.0)
├── run_gate_analysis.py                    # Gate charge/discharge (V9.0)
├── run_summing_node.py                     # Summing node sweep (V9.0)
├── run_rc_filter.py                        # LEB filter delay (V9.0)
├── data_factory.py                         # Parametric sweep (204 sims)
├── train_ai.py                             # Surrogate model training
├── evaluate_ai.py                          # Parity plot evaluation
├── predict.py                              # Instant CLI predictor
├── analyze_results.py                      # Modulation comparison
├── inverter_ai_model.pkl                   # Trained model binary
├── CHANGELOG.md
└── README.md
```

---

## How to Run

### Requirements
- [NgSpice](https://ngspice.sourceforge.io/) v44 or later (Windows 64-bit)
- [KiCad](https://www.kicad.org/) 9.0 or later (for hardware files)
- Python 3.10 or later
- `pip install matplotlib numpy scikit-learn`

### Inverter Simulation

```bash
# Batch mode (auto-plots and saves PNG)
python run_simulation.py

# Interactive NgSpice mode
ngspice src/H_Bridge_Full.cir
run
plot v(OUT_A, OUT_B)
plot v(Thermal_Power_In) v(Case_Temp) v(Heatsink_Temp)
```

### MPPT Booster — Feed-Forward PI (V8.0)
```bash
python run_mppt_sim.py
# Edit src/MPPT_Booster.cir to select input profile (120V / 250V / 350V)
```

### UC3843 Control Loop Tests (V9.0)
```bash
python run_mppt_uc3843.py       # Full closed-loop booster dashboard
python run_gate_analysis.py     # IGBT gate charge/discharge analysis
python run_summing_node.py      # dsPIC summing node 4-point sweep
python run_rc_filter.py         # LEB 470ns propagation delay
```

### Surrogate Model
```bash
python data_factory.py          # Generate 204-simulation training dataset
python train_ai.py              # Train and save Random Forest model
python predict.py               # Instant performance predictor CLI
```

---

## NgSpice Compatibility Notes
- `limit()` function is **not supported** in NgSpice 46 B-source expressions.
- `sdt()` integrator is **not available** — use G-source + Capacitor model.
- `.PARAM` variables **cannot** be referenced inside B-source expressions — hardcode values directly.
- Tested on: NgSpice 44 and 46 (Windows 64-bit).

---

## Roadmap

- [x] NgSpice environment and SPICE library structure
- [x] Half-bridge ideal switching — basic SPWM
- [x] Physical IGBT modeling (FGY75T120SWD)
- [x] Full H-Bridge — unipolar SPWM, LC filter, motor load
- [x] Closed-loop PI voltage regulation
- [x] ZMPT101B sensor delay modeling (200µs)
- [x] Dead-time implementation (~2µs, mirrors dsPIC DTCON1)
- [x] Short-circuit protection (CT + comparator + INT0 latch)
- [x] Electro-thermal IGBT model (Foster RC network)
- [x] Automated .meas metrics extraction
- [x] Python batch automation pipeline
- [x] Dead-time compensation (current-direction dependent)
- [x] Third harmonic injection (1/6th flat-top modulation)
- [x] Parametric data factory (204-simulation dataset)
- [x] Surrogate model training and predictor (Scikit-Learn)
- [x] 4kW MPPT boost converter — feed-forward + PI, 3 test profiles
- [x] UC3843 analog controller — closed-loop peak-current-mode control
- [x] KCL summing node — dsPIC PWM MPPT injection with boot-up safety
- [x] Asymmetric gate drive characterization — Miller plateau analysis
- [x] Leading Edge Blanking — 470ns INA181 filter delay validation
- [x] KiCad PCB layout — booster control board (DRC-clean)
- [ ] Hardware prototype assembly and bench validation against simulation
- [ ] Simulation-vs-hardware correlation report

---

## Engineering Documentation

| Document | Description |
|:---|:---|
| [MPPT Booster Engineering Report](docs/MPPT_Booster_Engineering_Report.md) | Full design report, controller parameters, firmware reference |
| [Bill of Materials](docs/MPPT_Booster_BOM_Purchasing_List.md) | Component purchasing list with supplier references |
| [Boost Inductor Calculations](docs/Boost_Inductor_Design_Calculations.md) | Core selection, winding calculations, saturation analysis |
| [UC3843 Hardware Guide](docs/UC3843_Hardware_Design_Guide.md) | Oscillator timing, slope compensation, pin-by-pin design |
| [INA181A2 Hardware Guide](docs/INA181A2_Hardware_Design_Guide.md) | Current sense amplifier design and PCB layout guidelines |

---

## Author

**Nadeem Tahir**

I have been designing and commissioning inverters, motor drives, and PLC-based industrial machines for 13 years. This project started as a way to validate my booster design before ordering PCBs, and grew into a simulation platform I now use across projects. I am working toward an MS/PhD in robotics and intelligent control.

Hardware: dsPIC30F2010, PIC, STM32, ESP32, Delta AS228T PLC.
Tools: NgSpice, KiCad, Python, Matplotlib, Scikit-Learn.

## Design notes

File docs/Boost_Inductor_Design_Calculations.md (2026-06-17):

# MPPT Boost Converter: Inductor Design Calculations

This document details the mathematical calculations used to determine the exact requirements for the main power inductor (L2) in the 4kW MPPT DC-DC Boost Converter.

## 1. Fixed System Parameters
* **Target Output Voltage (V_out):** 380V DC
* **Switching Frequency (f_sw):** 20,000 Hz (20 kHz)
* **Estimated Efficiency (n):** 0.95 (95%)

---

## 2. Dynamic Input Scenarios (Firmware Controlled)
The MCU dynamically limits power based on the available input voltage from the solar panels. We evaluate the two extreme scenarios:

* **Scenario A (2 Panels):** V_in = 100V, Maximum Power (P_out) = 1000W
* **Scenario B (4 Panels):** V_in = 200V, Maximum Power (P_out) = 3000W

---

## 3. Maximum Input Current (I_in) Calculation
**Formula:** `I_in = P_out / (V_in * n)`

* **Scenario A (100V, 1000W):**
  I_in = 1000 / (100 * 0.95)
  I_in = 10.52 Amps

* **Scenario B (200V, 3000W):**
  I_in = 3000 / (200 * 0.95)
  I_in = 15.78 Amps

*Conclusion:* The maximum continuous DC current the inductor will see is safely limited by the firmware to **~16 to 18 Amps**.

---

## 4. Duty Cycle (D) Calculation
**Formula:** `D = 1 - (V_in / V_out)`

* **Scenario A (100V):**
  D = 1 - (100 / 380)
  D = 0.736  (73.6% Duty Cycle)

* **Scenario B (200V):**
  D = 1 - (200 / 380)
  D = 0.473  (47.3% Duty Cycle)

---

## 5. Required Inductance (L) Calculation
**Formula:** `L = (V_in * D) / (f_sw * Delta_IL)`
*(Where Delta_IL is the allowed peak-to-peak current ripple. We design for a maximum ripple of 8 Amps).*

* **Worst-Case Ripple Calculation (Scenario B):**
  L = (200 * 0.473) / (20000 * 8)
  L = 94.6 / 160000
  L = 0.000591 Henries
  **L = 591 µH**

* **Low Power/Tighter Ripple Calculation (Scenario A, assuming 4A ripple):**
  L = (100 * 0.736) / (20000 * 4)
  L = 73.6 / 80000
  L = 0.00092 Henries
  **L = 920 µH**

*Conclusion:* The target inductor value for stable operation across all dynamic conditions is **600 µH to 1000 µH (1 mH)**.

---

## 6. Peak Saturation Current (I_peak)
To prevent the magnetic core from saturating (which would destroy the IGBTs), the inductor must handle the absolute peak of the current ripple.

**Formula:** `I_peak = I_in_max + (Delta_IL / 2)`

I_peak = 18A + (8A / 2)
I_peak = 18A + 4A
**I_peak = 22 Amps**

---

## 7. Physical Layout Requirements
Based strictly on the mathematics above, the physical hardware assigned to `L2` in the PCB layout must meet the following criteria:

1. **Wire Gauge:** Must be at least 12 AWG (or dual 14 AWG strands) to safely carry 18A RMS without overheating.
2. **Core Saturation:** Must be rated for > 25A peak saturation current.
3. **Physical Footprint Size:** Winding 1 mH of 12 AWG wire requires a massive core volume. The outer diameter of the toroid will be approximately **45mm to 60mm**. The PCB footprint MUST accommodate a minimum of 40mm pin-pitch to prevent mechanical stress on the board.

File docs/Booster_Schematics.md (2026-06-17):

# 4000W Chinese MPPT Booster Architecture

This document serves as the master design reference for the 4kW MPPT Card used in modern high-voltage solar hybrid inverters (e.g., Voltronic Axpert, Growatt).

## 1. System Block Diagram

```mermaid
graph TD
    PV["PV Input (120V - 400V)"] --> Precharge["Soft-Start Precharge Relay Stage"]
    Precharge --> Boost["Power Stage (Inductor + IGBTs + Diode)"]
    Boost --> DCBus["400V DC Bus Output"]
    
    Sub1["+20V Aux Supply"] --> GateDrive["Isolated Gate Driver (FOD3150)"]
    DSP["DSP / Main Controller (PWM)"] --> GateDrive
    GateDrive --> Boost
    
    Boost --> Sense["TL072 Voltage & Current Sensing"]
    Sense --> DSP
```

---

## 2. Stage 1: Soft-Start Pre-Charge Schematics

The pre-charge circuit prevents catastrophic inrush currents into the empty 400V DC bus capacitors when the solar panels are first connected.

```text
SOLAR (+) ───┬───────────────────────────────────┬─────────► To Inductor
             │                                   │
             │     ┌───[ 50Ω / 50W Resistor ]──┐ │
             │     │                           │ │
             └─────┼──── RELAY CONTACTS ───────┼─┘
                   │       (NO State)          │
                   └───────────────────────────┘
                           │
                         RELAY COIL
                           │
                      [Precharge CTRL]
```
**Function:** 
1. At power ON, the relay is open. Current flows through the 50Ω resistor, safely charging the massive 400V capacitors.
2. Once the DC Bus reaches ~350V, the controller clicks the relay closed.
3. The 50Ω resistor is bypassed, allowing the full 35A current to flow freely.

---

## 3. Stage 2: Main Boost Power Stage Scheme

This is the core MPPT boosting mechanism using dual-parallel IGBTs.

```text
From Pre-charge  ──┬─────────────────[ L1: 500µH / 50A ]──────────┬───────────► +400V DC BUS
(120V - 400V)    │                   (Toroidal Core)              │
                 │                                                │
               ──┴── C_in                                         │  D1
               ──┬── (470µF / 400V)                             ──┴── Diode (STTH3006D)
                 │                                              ──┬── 600V / 30A 
                 │                                                │
                 │              DRAIN/COLLECTOR                   │
                 │                 ┌───────────────┬──────────────┘
                 │                 │               │
                 │               │-│              │-│
                 │           Q1  │ │          Q2  │ │
                 │ (STGW60H65DFB)│ │(STGW60H65DFB)│ │
                 │               │ │               │ │
                 │               ─┬─              ─┬─
                 │    GATE        │                │
[PWM from FOD3150] ────┬─[22Ω]────┤                │
                       │          │                │
                       └─[22Ω]────┤                │
                                  │                │
                                  └────────┬───────┘
                                           │
SOLAR (-) ───────┴─────────────────────────┴──────────────────────────┴───────► GND
                 │                                                    │
                 │                                                  ──┴── C_out
             GND (Earth/Chassis)                                    ──┬── (4x 220µF / 450V)
                                                                      │
                                                                     GND
```
**Function:** 
- The IGBTs are pulsed at `~20kHz`.
- When closed, energy is stored in `L1` (500µH).
- When open, `L1` discharges through the `STTH3006D` ultrafast diode into the 400V DC Bus capacitors.
- Parallel IGBTs divide the thermal dissipation evenly.

---

## 4. Stage 3: Isolated Gate Drive (FOD3150)

To fully saturate the IGBTs, a robust 20V isolated drive is essential.

```text
                  +20V (Aux Supply)
                       │
                       │
             ┌─────────┴─────────┐
             │ 8) VCC        6)VO├───► To IGBT Gates (via 22Ω Resistors)
             │                   │
DSP PWM ─────┤ 2) ANODE          │      
             │      FOD3150      │
 GND ────────┤ 3) CATHODE    5)VE├───► To IGBT Emitters (Power GND)
             │                   │
             └───────────────────┘
```
**Function:**
- Provides optical isolation between the low-voltage DSP control board and the high-voltage IGBTs.
- Drives the gate with a +20V hard saturation pulse, ensuring zero switching loss due to slow turn-on.

---

## 5. Stage 4: Voltage & Current Sensing (TL072)

```text
        [470kΩ]                              [ACS712-30A or Hall Sensor]
           │                                          │
+400V ─────┤      Voltage Divider                     ├──► Current Signal (0-3.3V)
           │      scales to 3.3V                      │
        [3.3kΩ]                                       │
           │                                          │
           ├────────► To TL072 (Op-Amp A)             ├────────► To TL072 (Op-Amp B)
           │          Buffer & Filtering              │          Scaling & Filtering
          GND                 │                                          │
                              ▼                                          ▼
                      To DSP ADC Pin 1                           To DSP ADC Pin 2
```
**Function:**
- Scales down the lethal 400V output to a safe, logic-level 3.3V reference.
- Filters switching noise using the `TL072` JFET dual op-amp before feeding the signals to the main processor's Analog-to-Digital Converter (ADC) for MPPT tracking.

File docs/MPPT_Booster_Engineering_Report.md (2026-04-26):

# 4kW MPPT DC-DC Boost Converter — Engineering Report

**Author:** Nadeem Tahir
**Revision:** 2.0 — April 2026
**Simulation:** NgSpice 46 (Windows 64-bit)
**Controller:** dsPIC30F2010 @ 20kHz

---

## 1. System Specifications

| Parameter | Value |
|:---|:---|
| Topology | Non-Isolated DC-DC Boost |
| Input Voltage | 120V – 350V DC (3–8 Panel PV String) |
| Output Voltage | 380V DC Link (regulated) |
| Max Power | 4000W |
| Switching Frequency | 20kHz |
| Power Switches | 2× STGW60H65DFB (650V/60A, parallel) |
| Boost Diode | STTH3006D (600V/30A, Trr=35ns) |
| Gate Driver | FOD3150 (optically isolated) |
| Inductor | 500µH (DCR ≤ 50mΩ) |
| Input Capacitor | 470µF |
| Output Capacitor | 880µF / 450V electrolytic |

---

## 2. Test Profiles

| Profile | V_in | Load  | R_load  | Boost Ratio | Duty Cycle |
|:---|:----:|:-----:|:---:|:---:|:---:|
| 3-Panel | 120V | 1500W | 96.27 Ω | 3.17× | 68.4% |
| 5-Panel | 250V | 3000W | 48.13 Ω | 1.52× | 34.2% |
| 8-Panel | 350V | 4000W | 36.10 Ω | 1.09× | 7.9% |

R_load = V²out / P = 380² / P

---

## 3. Startup State Machine

```
  STATE_IDLE ──▶ STATE_PRECHARGE ──▶ STATE_RELAY_CLOSE ──▶ STATE_RAMPING ──▶ STATE_RUNNING
  (IGBTs OFF)    (50Ω soft-start)    (Bypass resistor)     (Feed-Fwd+PI)    (Load ON)
```

| State | Duration | Action |
|:---|:---|:---|
| IDLE | — | Wait for V_PV > 80V |
| PRECHARGE | 20ms | Charge C_OUT through 50Ω. IGBTs locked OFF. |
| RELAY_CLOSE | Instant  | GPIO fires relay. 50Ω bypassed. |
| RAMPING | 130ms | Voltage ramp from V_in toward 380V. |
| RUNNING | Steady | Load contactor closes. Full regulation. |

**Critical Rule:** Load contactor must NOT close until V_bus ≥ 342V (90% of target). Early load connection causes 400A+ surge currents.

---

## 4. Control Architecture

### Feed-Forward + PI

The boost duty cycle is deterministic: **D = 1 − V_in / V_out**

The feed-forward pre-computes this baseline. The PI controller handles ±2% trim corrections only.

**Key constraint:** Feed-forward must track the **ramp target**, not the fixed 380V target. Using a fixed target demands 68% duty at t=0 (when output is still at V_in), causing instant overshoot.

Correct formula:
```
D_ff = 1 − V_in / V_ramp_target
```

| Ramp Position | Physical Target | D_ff (at 120V) |
|:---:|:---:|:---:|
| Start | 120V | 0.00 |
| 25% | 185V | 0.35 |
| 50% | 250V | 0.52 |
| 75% | 315V | 0.62 |
| 100% | 380V | 0.684 |

### SPICE Implementation

```spice
* Feed-Forward: D = 1 - Vin / (RAMP_ADC * 301)
B_FF FF_DUTY 0 V = V(RAMP_NODE) > 0.1 ? (1.0 - V(IN_SOFT)/(V(RAMP_NODE)*301)) : 0.0

* Combined: Feed-Forward + PI Trim
B_PI_Raw PI_RAW 0 V = V(FF_DUTY) + 0.2 * V(ERR) + V(INT_CLAMPED)

* Hard Limits
B_PI_Safety PI_SAFE 0 V = V(PI_RAW) > 0.90 ? 0.90 : (V(PI_RAW) < 0.0 ? 0.0 : V(PI_RAW))
```

### Voltage Divider Scaling

```
V_physical ──┬── 3× 1MΩ = 3MΩ ──┬── V_ADC ──▶ AMC1311 ──▶ dsPIC AN0
             └───────────────────┴── 10kΩ ──▶ GND

V_ADC       = V_physical × 0.003322
V_physical  = V_ADC × 301
```

| V_physical | V_ADC  |
|:---:|:---:|
| 120V | 0.398V |
| 250V | 0.830V |
| 380V | 1.262V |
| 400V (max) | 1.329V |

---

## 5. Controller Design Parameters

| Parameter | Value | Notes |
|:---|:---|:---|
| Kp | 0.2 | Proportional — trim correction only |
| Ki | 0.005 | Integral — conservative to prevent windup|
| Duty Max | 90% | Shoot-through margin |
| Duty Min | 0% | Allows full IGBT shutdown (see §6.2) |
| EMA Filter α | 0.015 | fc = 48Hz at 20kHz ISR (see §6.3) |
| V_target (ADC) | 1.262V  | = 380V × 0.003322 |
| OVP Trip (ADC) | 1.40V | = 422V — immediate IGBT shutdown |
| Precharge Duration  | 20ms | 400 ISR ticks at 20kHz |
| Ramp Duration | 130ms | 2600 ISR ticks |

**Control equation (per ISR tick):**
```
D_ff    = 1 − V_in / V_ramp_target
error   = V_target − V_bus_filtered
D_total = D_ff + Kp × error + ΣKi × error
D_out   = clamp(D_total, 0.00, 0.90)
```

---

## 6. Critical Findings

### 6.1 Timestep Resolution

IGBT and gate driver models contain internal RC networks requiring sub-microsecond resolution. At 1µs timestep, the IGBT produces near-zero current despite correct duty cycle.

**Solution:** Separate output and internal steps:
```
tran 10u 200ms 0 100ns uic
```
Output: 10µs intervals. Internal physics: 100ns max step.

### 6.2 Minimum Duty Cycle = 0%

A 5% floor causes continuous voltage drift when unloaded. At 5% duty from 120V, ~15W is pumped into the capacitor with no drain.

**Solution:** Set `DUTY_MIN = 0.0f` to allow complete IGBT shutdown.

### 6.3 350V Oscillation (8-Panel)

At 350V/4000W, the DC bus oscillates ±10V after load connection. Root cause: LC resonance at 221Hz falls within PI bandwidth, and the feed-forward provides only 7.9% baseline — leaving the PI controller exposed to the full load transient.

**Why it is safe:** Voltage stays within 370–390V (under 450V cap rating). Oscillation is bounded, not growing.

**Firmware fix (single line):**
```c
vbus_filt = 0.015f * vbus_raw + 0.985f * vbus_filt;
```
This EMA filter (fc=48Hz) attenuates the 221Hz resonance by −13dB, eliminating the oscillation entirely.

### 6.4 Inductor DCR Damping

Real inductors have 20–80mΩ DCR. Adding 50mΩ DCR in simulation provides natural LC damping. Power loss at 12A average: P = I²R = 7.2W (0.18% of 4kW — negligible).

---

## 7. Hardware Checklist

### Power Stage
- [ ] Output capacitor rated ≥ 450V
- [ ] Gate resistors: 2× 22Ω parallel (11Ω effective) from FOD3150 to IGBT gate
- [ ] Soft-start: 50Ω / 5W resistor with bypass relay (≥15A @ 350V)
- [ ] Load contactor controlled by GPIO — not permanently wired
- [ ] 10kΩ pull-down from IGBT gate to emitter (prevents floating latch-up)
- [ ] 100nF ceramic on FOD3150 VCC and dsPIC VDD

### Sensing
- [ ] Voltage divider: 3× 1MΩ + 10kΩ (1% metal film)
- [ ] Anti-aliasing filter: 10kΩ + 330nF C0G (NOT X7R) between AMC1311 and dsPIC AN0
- [ ] Firmware EMA filter before ALL PI calculations

### ADC Filter Wiring
```
AMC1311 VOUT+ ──[10kΩ]──┬── dsPIC AN0
                        │
                    [330nF C0G]
                        │
                      GND_LV
```
fc = 1 / (2π × 10kΩ × 330nF) = 48Hz

---

## 8. Simulation Results

| Profile | V_in | Load  | Ramp | Load Transient | Steady State | Verdict  |
|:---|:----:|:-----:|:---:|:---:|:---:|:---:|
| 3-Panel | 120V | 1500W | Smooth | 40A spike (safe) | 380V flat | **PASS** |
| 5-Panel | 250V | 3000W | Smooth | Clean | 380V flat | **PASS** |
| 8-Panel | 350V | 4000W | Smooth | ±10V oscillation†  | 380V avg | **PASS** |

† Eliminated in firmware by EMA filter (Section 6.3)

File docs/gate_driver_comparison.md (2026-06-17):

# Gate Driver Technical Comparison: FOD3150 vs. TLP250H
**Analysis for 4kW Parallel IGBT MPPT Booster**

When driving two 60A IGBTs in parallel, the combined Gate Charge ($Q_g$) is doubled. To switch them instantly without lingering in the linear region (which causes massive heat), the gate driver must be able to instantly output a massive spike of current.

Here is the exact datasheet comparison of the two ICs:

| Parameter | FOD3150 (Fairchild/OnSemi) | TLP250H (Toshiba) | Winner / Impact on 4kW Inverter |
| :--- | :--- | :--- | :--- |
| **Peak Output Current** | 1.0 A (Min) / 1.5 A (Typ) | **2.5 A (Max)** | **TLP250H wins.** The 2.5A rating means it can dump charge into two parallel IGBTs much faster than the FOD3150. |
| **Common Mode Transient Immunity (CMTI)** | 20 kV/µs | **40 kV/µs** | **TLP250H wins.** When your IGBT switches 400V in nanoseconds, it creates a massive $dV/dt$ noise spike. The TLP250H is twice as immune to noise crashing the microcontroller. |
| **Max Propagation Delay** | 500 ns | 500 ns | **Tie.** Both are fast enough for 20kHz SPWM. |
| **Supply Voltage Range** | 15V to 30V | 10V to 30V | **TLP250H wins.** It can operate safely down to 10V if the auxiliary power supply dips. |
| **Pin Configuration** | 8-pin DIP | 8-pin DIP | **Identical.** They are drop-in replacements for each other. |

### Engineering Conclusion:
In our previous NgSpice simulation, we used the FOD3150 because its mathematical SPICE model was readily available. 
However, for your physical 4kW hardware design, **your choice of the TLP250H is vastly superior.** Its 2.5A peak current is exactly what we need to drive two parallel IGBTs safely.

You made an excellent engineering decision using the TLP250H in your H-Bridge. We will definitely use the TLP250H for this MPPT booster!

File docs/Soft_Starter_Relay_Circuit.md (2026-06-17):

# Detailed Component-Level Schematic: Soft-Start Precharge Circuit

This document details the exact, component-level schematic required to safely drive the high-power 40A precharge relay from a delicate 3.3V/5V dsPIC30F2010 microcontroller pin.

## 1. The Schematic

## 1. Professional Graphical Schematic (Similar to your referenced format)

Here is the exact circuit rendered as a professional Electronic Design Automation (EDA) vector schematic:

Soft Start Circuit Diagram
                               +12V_AUX
                                  |
               +------------------+------------------+
               |                                     |
               |                                     |
             +---+ (Cathode)                        [#]  K1
             | _ | D1                               [#] (Relay Coil)
             |/ \| 1N4007                           [#]
             +---+                                   |
               |                                     |
               |                                     |
               +------------------+------------------+
                                  |
                                | / C
                      Q1      B |/
  [dsPIC MCU] ----/\/\/\/\------|   2N2222 (NPN)
                  R1 (1k)       |\
                                | \ E
                                  v
                                  |
                                 ===
                                 GND 
                                 
========================== HV ISOLATION BOUNDARY ==========================

                                    K1 (NO Contacts)
                                 ________/ ________
                                |                  |
PV_IN (+) ----------------------+                  +-------> To L1 (Boost Inductor)
(120V-400V DC)                  |                  |
                                |                  |
                                +----/\/\/\/\/\----+
                                      R2 (50 Ohm)
                                    (50W Pre-Charge)
```

---

## 2. Component Breakdown & Bill of Materials (BOM)

### The Low-Voltage Logic Side
1. **R1 (1kΩ Base Resistor):** Restricts the current leaving the fragile DSP pin to exactly ~4mA so you don't burn out the dsPIC30F2010.
2. **Q1 (NPN Transistor, e.g., 2N2222A or BC547):** A dsPIC pin cannot output the ~100mA required to physically move the massive electromagnet coil inside a 40A relay. The transistor acts as an amplifier switch. When the DSP sends 5V, the transistor seamlessly connects the relay coil to GND, powering it on.
3. **D1 (1N4007 Freewheeling Diode):** **CRITICAL SAFETY COMPONENT.** When the transistor turns OFF, the relay coil's magnetic field collapses and generates a massive negative voltage spike (up to -200V). The 1N4007 safely diverts this lethal spike in a circle until it dissipates, preventing the transistor and DSP from exploding.

### The High-Voltage Power Side
4. **Relay (e.g., SLA-12VDC-SL-A  or  JQX-105F-1):** 
   - **Coil:** 12V DC.
   - **Contacts:** 40A rating. This relies completely on physical zero-ohm metal contacts, meaning no overheating at 35 Amps continuous load.
5. **Pre-charge Resistor (50Ω / 50 Watt):** This heavy aluminum-cased, wire-wound resistor easily handles the 8 to 15 Amp initial surge for the brief 1-2 seconds it takes to charge the main DC bus capacitors before the relay clicks shut.

---

## 3. The Sequence of Operation
1. **Cold State:** MCU pin is `LOW`. Transistor is `OFF`. Relay coil is unpowered. Contacts are open.
2. **PV Breaker Turned ON:** Solar electricity passes exclusively through the `50Ω` resistor. The 400V capacitors charge gently over ~1 second without arcing.
3. **Bus Confirmed Charged:** MCU measures the bus. Once safe, it drives the MCU pin `HIGH`.
4. **Relay Engagement:** Transistor `Q1` activates, pulling the 12V coil to GND. The Relay contacts snap shut, permanently shorting out (bypassing) the 50Ω resistor.
5. **Full Operation:** 100% of the heavy 4000W load current now flows strictly through the relay contacts. The resistor rests at zero current, zero heat format.

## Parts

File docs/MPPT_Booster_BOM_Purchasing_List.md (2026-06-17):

# 4kW MPPT Booster — Bill of Materials (BOM) & Purchasing List

**Project:** 4kW MPPT DC-DC Boost Converter (dsPIC30F2010 + UC3843)
**Date:** April 2026
**Target Market:** Hall Road, Lahore / AliExpress

---

## 1. The "Hard to Find" Components (Check Hall Road First, then AliExpress)
*These parts are critical for the Micro-Shunt sensing method. Hall Road usually does not stock these. If unavailable, order online.*

| Item | Part Number / Specs | Qty per Board | AliExpress / Online Notes | Hall Road Backup Option |
| :--- | :--- | :--- | :--- | :--- |
| **Current Sense Amp** | **TI INA181A2IDBVR** (SOT-23-6) | 1 | Search: "INA181A2IDBVR". Make sure top mark is `1AED` (Gain = 50). | **None.** Must build Current Transformer (CT) instead. |
| **Micro-Shunt Resistors** | **2mΩ (R002)**, 2512 SMD, 1% Alloy, 2W | 5 | Search: "2512 alloy resistor R002". Solder all 5 in parallel. | Buy generic Manganin wire from multimeter repair shops. |

---

## 2. Core Control ICs & Gate Drivers
*These are generally available at major IC shops on Hall Road (e.g., EVE-II, Ahtesham Electronics).*

| Item | Part Number / Specs | Qty | Notes |
| :--- | :--- | :--- | :--- |
| **Analog PWM Controller** | **UC3843** | 1 | Standard DIP-8 or SOIC-8. Ask for original ST or TI if possible. |
| **Microcontroller** | **dsPIC30F2010** | 1 | Existing brain for your inverter / MPPT algorithm. |
| **Isolated Gate Driver** | **FOD3150** or **TLP250H** | 1 | Must be isolated. TLP250H is very common on Hall Road. |
| **Fast Switching Diodes** | **1N4148** | 3 | Used for asymmetric gate turn-off path. Buy a strip of 50. |

---

## 3. Power Stage (High Voltage / High Current)
*Available at heavy electronics/inverter repair shops in the market.*

| Item | Part Number / Specs | Qty | Notes |
| :--- | :--- | :--- | :--- |
| **Main Switching IGBTs** | **STGW60H65DFB** (650V, 60A) | 2 | Parallel configuration. Or equivalent TO-247 Field Stop Trench IGBTs. |
| **Boost Fast Diode** | **STTH3006D** (600V, 30A) | 1 | Ultra-fast recovery is MANDATORY. Do not use standard rectifiers. |
| **Input Capacitors** | **470µF / 450V** Electrolytic | 2 | High ripple current rating if possible. |
| **Output Capacitors** | **470µF / 450V** Electrolytic | 2 | (Two in parallel = 940µF). Must handle 380V DC safely. |
| **Pre-Charge Resistor** | **50Ω, 10W or 20W** | 1 | Standard white rectangular cement resistor. |
| **Pre-Charge Relay** | **30A, 12V Coil Relay** | 1 | SLA-12VDC-SL-A or similar heavy-duty PCB relay. |

---

## 4. Passive Components (Gate Drive & Filtering)
*Easily available everywhere.*

| Item | Value / Specs | Qty | Purpose |
| :--- | :--- | :--- | :--- |
| **Turn-ON Resistor** | **15Ω** (1/4W or 1/2W) | 2 | Limits di/dt turn-on spike. |
| **Turn-OFF Resistor** | **5.6Ω** (1/4W or 1/2W) | 2 | Fast Miller-discharge path. |
| **Gate Pull-Down** | **10kΩ** (1/4W) | 2 | Solder directly across Gate-Emitter to prevent ghost turn-on. |
| **RC Filter Resistor** | **150kΩ** (1/2W) | 1 | UC3843 Voltage Feedback divider (High side). |
| **RC Filter Resistor** | **1kΩ** (1/4W) | 1 | UC3843 Voltage Feedback divider (Low side). |

---

## 5. The "Plan B" Current Transformer (CT) Parts
*If you cannot find the INA181 on Hall Road and do not want to pay AliExpress delivery taxes, buy these parts to wind a CT instead.*

| Item | Specs | Qty | Notes |
| :--- | :--- | :--- | :--- |
| **Ferrite Toroidal Core** | Medium size (approx 1-inch diameter) | 1 | From transformer winding shops. Must be ferrite, not iron powder. |
| **Enamelled Copper Wire** | Thin gauge (e.g., 28 SWG) | 1 roll | For winding 100 turns around the core. |
| **CT Burden Resistor** | **2Ω** (1 Watt) | 1 | Converts the 0.5A CT secondary current into 1.0V for the UC3843. |
| **CT Reset Diode** | **1N4148** | 1 | Placed across the burden resistor. |

---
*Created for Hall Road Purchasing Run - April 2026*

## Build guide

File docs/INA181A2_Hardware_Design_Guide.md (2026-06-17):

# Hardware Design Guide: INA181A2 Current Sense Amplifier

This document provides the exact pinout, electrical requirements, and PCB layout rules for integrating the **Texas Instruments INA181A2IDBVR** into the 4kW MPPT Booster.

## 1. Pin Diagram (SOT-23-6 Package)

The INA181 comes in a tiny 6-pin surface mount package. Looking at the top of the chip (with the text `1AED` readable and the dot indicating Pin 1 in the bottom left):

```text
         +---+--+---+
   OUT --| 1      6 |-- REF
         |          |
   GND --| 2      5 |-- IN-
         |          |
    VS --| 3      4 |-- IN+
         +----------+
```

## 2. Pin-by-Pin Wiring Configuration

| Pin | Name | Connection in Your Circuit | Important Notes |
| :--- | :--- | :--- | :--- |
| **1** | **OUT** | To **Pin 3 (ISENSE)** of UC3843 | **CRITICAL:** Do not connect directly! You must use an RC filter (1kΩ resistor in series, 470pF capacitor to ground) to filter out the IGBT turn-on spike. |
| **2** | **GND** | **Analog Ground** | Tie to the clean analog ground. Do not tie to the noisy high-power IGBT ground plane. |
| **3** | **VS** | **+5V DC Supply** | **WARNING:** The INA181 has a maximum supply of 5.5V. **Do NOT connect this to the 15V UC3843 supply.** You must connect this to the clean 5V rail (the same rail powering your dsPIC). Must have a `0.1µF` ceramic capacitor placed right next to Pin 3 and Pin 2. |
| **4** | **IN+** | **Shunt (High Side)** | Connect to the side of the 0.4mΩ shunt facing the **IGBT Emitters**. |
| **5** | **IN-** | **Shunt (Low Side)** | Connect to the side of the 0.4mΩ shunt facing **Main Power Ground**. |
| **6** | **REF** | **Ground (GND)** | **CRITICAL:** Because current only flows in one direction (unidirectional), tie this pin directly to **Pin 2 (GND)**. This tells the chip that 0 Amps = 0 Volts output. |

## 3. The Schematic (ASCII Representation)

```text
                      +5V Supply
                           │
                           │
                        +--+--+                 R_Filter
                        |     |                  (1kΩ)
               +--------|VS   |        +-------[WWWWWW]--------+---> To UC3843 Pin 3
               |        |     |        |                       |
              ===       |  OUT|--------+                      ===  C_Filter
             0.1µF      |     |                              470pF
               |        |     |                                |
               +--------|GND  |                                |
               |        |     |                                |
              GND       |  REF|--------------------------------+---> GND
                        |     |               
               +--------|IN+  |              
               |        |     |
               |   +----|IN-  |
               |   |    +-----+
               |   |
IGBT Emitters  |   |
  (Main High)  |   |
     │         │   │
     +----[ 5x 2mΩ SMD Resistors ]----+
                                      │
                                  Main Power Ground
```

## 4. The Leading Edge Spike Filter (Pin 1 OUT)

When the IGBT turns ON, the reverse recovery of the diode and parasitic capacitances cause a massive, invisible 100ns current spike. If this spike reaches the UC3843, it will falsely shut down the PWM.

To prevent this, you **must** place an RC Low-Pass Filter between the INA181 output and the UC3843 Pin 3:
1.  **Series Resistor:** `1 kΩ`
2.  **Capacitor to Ground:** `470 pF` (Place this ceramic capacitor as close to Pin 3 of the UC3843 as physically possible).
This creates a ~470ns delay filter—enough to hide the turn-on noise, but fast enough to protect against a real short circuit.

## 5. Critical PCB Layout Rules (Kelvin Connection)

When you design the PCB, the way you connect Pin 4 (`IN+`) and Pin 5 (`IN-`) to the SMD resistors is the difference between success and failure.

1. **Kelvin Sensing:** Do NOT just connect `IN-` to the nearest ground plane. You must draw a dedicated, thin copper trace directly from the inner edge of the copper pad of the SMD resistors directly to the `IN-` pin. Do the same for `IN+`. 
2. **Differential Pair:** Route the `IN+` and `IN-` traces right next to each other (parallel) all the way from the resistors to the IC. This ensures that any EMI from the IGBTs hits both traces equally, allowing the INA181's 100dB Common-Mode Rejection to perfectly cancel out the noise.
3. **Trace Length:** Place the INA181 chip as physically close to the 5 SMD resistors as possible. The traces should be very short.

## 5. Electrical Summary for this Design
*   **Shunt Value:** 0.4 mΩ (Five 2mΩ resistors in parallel)
*   **Amplifier Gain:** 50 V/V (Fixed internally in the INA181A2)
*   **Output Equation:** `V_out = (Current × 0.0004) × 50`
*   **Result:** 10A = 0.2V | 25A = 0.5V | 50A = 1.0V (Hardware Shutdown Threshold)

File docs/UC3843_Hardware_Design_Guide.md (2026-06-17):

# Hardware Design Guide: UC3843 Analog Controller

This document provides the exact pinout, electrical requirements, and external supporting component list for integrating the **UC3843** into the 4kW MPPT Booster. 

This circuit configures the UC3843 as a "Hardware Slave" to the dsPIC30F2010. The dsPIC commands the target voltage, but the UC3843 handles all the nanosecond-level switching, dead-time, and peak current protection.

## 1. Pin Diagram (DIP-8 / SOIC-8)

```text
            +---+--+---+
       COMP | 1      8 | VREF (5.0V)
            |          |
 VFB (from) | 2      7 | VCC (15V)
   (dsPIC)  |          |
     ISENSE | 3      6 | OUT (to Gate Driver)
            |          |
      RT/CT | 4      5 | GND
            +----------+
```

## 2. Pin-by-Pin Wiring & External Components

| Pin | Name | External Components Required | Purpose & Connection |
| :--- | :--- | :--- | :--- |
| **1** | **COMP** | `100kΩ` Resistor + `10nF` Capacitor in series to Pin 2 | **Error Amplifier Compensation.** Stabilizes the internal op-amp so it doesn't oscillate when the dsPIC changes the voltage. |
| **2** | **VFB** | RC Filter from dsPIC `OC1` pin + `10kΩ` Pull-Up to VREF | **Voltage Feedback.** The dsPIC feeds a filtered DC voltage here. **CRITICAL:** You must add a 10kΩ pull-up to Pin 8 (VREF) for boot safety. |
| **3** | **ISENSE** | `1kΩ` + `470pF` (LEB Filter) + Slope Comp Resistor | **Current Protection.** Receives the 0-1V signal from the INA181. Shuts off the IGBT instantly if it hits 1.0V (50A). |
| **4** | **RT/CT** | `Rt = 8.6kΩ` to Pin 8.<br>`Ct = 10nF` to GND. | **Oscillator (20 kHz).** These two components set the main switching frequency. |
| **5** | **GND** | None | **Ground.** Tie to the main clean analog ground. |
| **6** | **OUT** | `1.3kΩ` Resistor to FOD3150 Pin 2 | **PWM Output.** Drives the LED inside the isolated FOD3150. (15V output - 1.5V LED = 13.5V. 13.5V / 1.3kΩ = ~10mA). |
| **7** | **VCC** | `10µF` Electrolytic + `0.1µF` Ceramic to GND | **Power Supply (15V).** Must be stable. The UC3843 turns on at 8.4V and turns off at 7.6V (UVLO). |
| **8** | **VREF** | `0.1µF` Ceramic to GND | **5.0V Reference.** Internal highly accurate 5V supply used to power the `Rt` resistor. |

---

## 3. The Complete Hardware Schematic (Modular View)

To make the layout perfectly clear for PCB design, the schematic is broken down into three functional modules.

```text
                 +-----------------------+
                 |                       |
      (COMP) 1 --|      UC3843           |-- 8 (VREF)
                 |                       |
       (VFB) 2 --|  PWM CONTROLLER       |-- 7 (VCC)
                 |                       |
    (ISENSE) 3 --|                       |-- 6 (OUT)
                 |                       |
     (RT/CT) 4 --|                       |-- 5 (GND)
                 +-----------------------+
```

### Module A: The MPPT Summing Node (Pin 1 & 2)
This module handles the 380V hardware regulation and the dsPIC MPPT injection logic.
```text
                            +---> To Pin 1 (COMP)
                            |
                     [10nF + 100kΩ]
                            |
[ 380V DC Bus ]---[ 1.5MΩ ]-+---> To Pin 2 (VFB)
                            |
    [ Ground ]----[ 10kΩ ]--+
                            |
                     [47kΩ Injection]
                            |
                         (Node A) --- [ 1µF Cap ] --- GND
                            |
                     [10kΩ Filter]
                            |
   [ dsPIC OC1 ]------------+-------- [ 10kΩ Pull-Up ] --- +5V
```

### Module B: Current Sense & Slope Compensation (Pin 3 & 4)
This module handles the nanosecond current protection and cures sub-harmonic oscillation.
```text
[ INA181 OUT ]---[ 1kΩ ]----+-------> To Pin 3 (ISENSE)
                            |
    [ Ground ]---[ 470pF ]--+
                            |
                     [10kΩ Slope Res]
                            |
                         [Emitter]
                           2N3904 NPN
                         [Base]   [Collector] ------> To Pin 8 (VREF)
                            |
                            +-----------------------> To Pin 4 (RT/CT)
                            |
                         [Rt 8.6kΩ] ----------------> To Pin 8 (VREF)
                            |
                         [Ct 10nF ] ----------------> Ground
```

### Module C: Power & Output (Pins 5, 6, 7, 8)
This module provides power and drives the isolated gate driver.
```text
        [ Ground ] <------------------------- Pin 5 (GND)

[ FOD3150 Pin 2 ] <-------[ 1.3kΩ ]---------- Pin 6 (OUT)

  [ +15V Power ] ---+------------------------ Pin 7 (VCC)
                    |
      [ Ground ] ---+---[ 10µF + 0.1µF ]

      [ Ground ] ---+---[ 0.1µF ]------------ Pin 8 (VREF)
```

### **Schematic Breakdown & Final Physics:**
*   **Pin 1 & 2 Loop:** The `10nF` capacitor and `100kΩ` resistor connect Pin 1 and Pin 2 together to stabilize the internal amplifier.
*   **Pin 2 (The Summing Node):** This relies on Kirchhoff's Current Law (KCL).
    1.  **380V Hardware Regulation:** A `1.5MΩ` resistor connects to the 380V DC Bus, and a `10kΩ` resistor connects to Ground. If the dsPIC is at 50% PWM, it becomes invisible, and this divider clamps the hardware at exactly 377V.
    2.  **dsPIC RC Filter:** The OC1 PWM signal first passes through a **`10kΩ` Filter Resistor** and a **`1µF` Filter Capacitor** to Ground. This flattens the 20kHz PWM into a perfectly smooth DC voltage.
    3.  **dsPIC Injection:** This smooth DC voltage connects to Pin 2 via a **`47kΩ` injection resistor**. By changing PWM from 0% to 100%, the dsPIC slides the hardware target voltage anywhere between 443V and 311V.
    4.  **Boot-Up Safety:** A **`10kΩ` Pull-Up resistor** is attached directly to the dsPIC OC1 pin to the +5V MCU power. If the dsPIC is booting (floating), this forces 5V through the filter, regulating the bus safely to 321V and keeping the system shut down.
*   **Pin 3 Input:** The INA181 current signal passes through a `1kΩ` resistor and `470pF` capacitor to ground to filter out 100ns Leading Edge Noise.
*   **Pin 3 & 4 (Slope Comp):** The `2N3904 NPN` transistor's Base connects to Pin 4 to read the 20kHz sawtooth wave without stealing current. Its Collector connects to Pin 8 (VREF) for muscle. Its Emitter connects through a `10kΩ` slope resistor to Pin 3 to cure sub-harmonic oscillation at >50% duty cycles.
*   **Pin 4 Timing:** An `8.6kΩ` resistor connects to Pin 8. A `10nF` capacitor connects to Ground. This guarantees exactly 20kHz switching.
*   **Pin 6 Output:** A `1.3kΩ` resistor connects directly to the LED input of the FOD3150. Since the UC3843 outputs 15V, this resistor safely limits the LED current to ~10mA.

## 4. The Slope Compensation Circuit (Deep Dive)
As discussed in Section 14.8, because you are boosting 150V to 380V (a duty cycle greater than 50%), you must add slope compensation to Pin 3 to prevent sub-harmonic oscillation.

**How to wire it:**
1.  **NPN Transistor:** Use a standard cheap NPN like a `2N3904`.
2.  **Base:** Connect to **Pin 4 (RT/CT)**. This picks up the 20kHz sawtooth wave.
3.  **Collector:** Connect to **Pin 8 (VREF)** or **Pin 7 (VCC)** for power.
4.  **Emitter:** Connect a `10kΩ` resistor from the Emitter to **Pin 3 (ISENSE)**.

*How it works:* It takes the oscillator's rising ramp and mixes a tiny bit of it into the current sensor's signal. This mathematically tricks the UC3843's internal comparators into remaining perfectly stable, even when the duty cycle climbs up to 90% during a cold start!

## 5. The "Dead-Boot" Explosion Risk (CRITICAL PCB FIX)
When reviewing Advanced Chinese inverter architectures (like Voltronic Axpert), they all implement a safety mechanism to prevent a "Dead-Boot Explosion."

**The Flaw:** When you turn the inverter on, the 15V supply wakes up the UC3843 instantly. However, the dsPIC30F2010 takes several milliseconds to boot up its software and output a signal on the OC1 pin. During these milliseconds, the `VFB` (Pin 2) is floating at `0V`. 
If `VFB` is `0V`, the UC3843 thinks the solar voltage has crashed, and it instantly goes to **100% MAXIMUM Duty Cycle**. Turning on a boost converter at 100% duty cycle is a dead short circuit across the solar panels. The IGBTs will explode before the dsPIC even finishes booting.

**The Tier-1 Solution:**
You **MUST** place a `10kΩ` Pull-Up resistor on the dsPIC OC1 PWM line (connected to your 5V MCU power). 
*   *Why this works:* Before the dsPIC boots, this resistor pulls the injection line to `5.0V`. This 5V feeds through the `47kΩ` injection resistor into Pin 2 (VFB), pushing the VFB node slightly above 2.5V. The UC3843 defaults to **0% Duty Cycle** (safely disabled). 
*   Once the dsPIC boots up, it drives the OC1 pin low or high, overpowering the pull-up resistor and taking proper control of the voltage.

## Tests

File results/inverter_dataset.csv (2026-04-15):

THI | DT_COMP | V_DC_Link | v_out_rms | v_out_peak | i_load_peak | i_load_rms | p_load_avg | p_dc_input | tj_max | tj_avg
0 | 0 | 350 | 168.139 | 251.6 | 6.42949 | 4.47557 | 400.951 | -412.462 | 45.6999 | 45.5528
0 | 0 | 352 | 168.988 | 252.076 | 6.46286 | 4.4974 | 405.074 | -416.536 | 45.7099 | 45.5614
0 | 0 | 354 | 169.912 | 255.851 | 6.49948 | 4.52531 | 410.5 | -421.668 | 45.7139 | 45.5641
0 | 0 | 356 | 170.834 | 256.387 | 6.54499 | 4.54855 | 414.495 | -425.781 | 45.7243 | 45.5715
0 | 0 | 358 | 171.782 | 259.296 | 6.57551 | 4.57107 | 418.641 | -430.106 | 45.7323 | 45.5796
0 | 0 | 360 | 172.867 | 260.843 | 6.60103 | 4.59903 | 423.99 | -435.506 | 45.7388 | 45.5853
0 | 0 | 362 | 173.472 | 261.68 | 6.63429 | 4.61871 | 427.217 | -439.238 | 45.7468 | 45.5901
0 | 0 | 364 | 174.296 | 262.117 | 6.66773 | 4.64058 | 431.366 | -443.35 | 45.7559 | 45.5967
0 | 0 | 366 | 175.231 | 262.41 | 6.69361 | 4.66539 | 436.031 | -448.167 | 45.7664 | 45.6029
0 | 0 | 368 | 175.94 | 265.322 | 6.73048 | 4.68733 | 440.303 | -452.501 | 45.7704 | 45.6098
0 | 0 | 370 | 176.964 | 266.512 | 6.7574 | 4.71254 | 444.872 | -457.313 | 45.7866 | 45.6184
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

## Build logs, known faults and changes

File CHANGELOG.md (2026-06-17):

# Changelog

All notable changes to this project are documented in this file.

---

## [V10.0] - 2026-06-17 (Hardware PCB — KiCad Integration)
- Added complete KiCad 9.0 PCB layout for 4kW MPPT booster control board (`hardware/kicad/`)
- Board passes Design Rule Check (DRC) — see `hardware/kicad/DRC.rpt`
- Added 3D renders of assembled PCB (`hardware/renders/`)
- Integrated hardware engineering documentation: BOM, inductor calculations, UC3843 and INA181A2 design guides
- Updated README to present full simulation-to-hardware engineering lifecycle
- Marked KiCad PCB roadmap item as complete

## [V9.0] - 2026-04-27 (UC3843 Analog Control Loop Integration)
- Added closed-loop UC3843 peak-current-mode control netlist (`src/MPPT_Booster_UC3843.cir`)
- Implemented and validated KCL summing node: dsPIC OC1 PWM shifts 380V target between 311V and 443V
- Proved cold-boot safety mechanism: 10kΩ pull-up forces Pin 2 above 2.50V trip threshold during MCU startup
- Simulated and validated 4-point duty cycle sweep (25%/50%/75%/100%) confirming active-low MPPT control law
- Added high-resolution gate capacitance charge/discharge analysis (`src/Gate_Analysis.cir`)
- Characterized Miller Plateau on STGW60H65DFB: threshold at 6.0V, plateau at ~9V, saturation at 15V
- Validated asymmetric gate drive time constants: τ_ON = 300ns (15Ω), τ_OFF = 112ns (5.6Ω + 1N4148)
- Added Leading Edge Blanking filter analysis (`src/RC_Filter_Test.cir`)
- Measured 470ns propagation delay of 1kΩ + 470pF LEB filter — masks IGBT turn-on transient noise
- Added 4 new automated Python analysis scripts with dark-background Matplotlib dashboards
- Added UC3843 Hardware Design Guide (`docs/UC3843_Hardware_Design_Guide.md`)
- Added INA181A2 Hardware Design Guide (`docs/INA181A2_Hardware_Design_Guide.md`)
- Updated project structure: 6 source netlists, 6 Python runners, 24 result graphs

## [V8.0] - 2026-04-21 (4kW MPPT Boost Converter)
- Added complete 4kW MPPT DC-DC boost converter simulation (`src/MPPT_Booster.cir`)
- Feed-forward + PI control architecture for 120V–350V PV input to 380V DC bus
- Three validated test profiles: 120V/1500W, 250V/3000W, 350V/4000W
- New component models: STGW60H65DFB IGBT, STTH3006D diode, FOD3150 gate driver
- 5-state startup state machine (Idle → Precharge → Relay → Ramp → Running)
- Soft-start pre-charge circuit with relay bypass
- Inductor DCR modeled for realistic LC damping (50mΩ)
- Full engineering report with firmware C code and hardware checklist
- Added `run_mppt_sim.py` for automated simulation with Matplotlib plotting
- Documented 350V oscillation root cause and firmware EMA filter solution
- New files: `docs/MPPT_Booster_Engineering_Report.md`

## [V7.0] - 2026-04-15 (Surrogate Model Training)
- Integrated Scikit-Learn Random Forest Regression model (`train_ai.py`).
- Trained model on 204-simulation physical dataset generated by `data_factory.py`.
- Built an interactive interface (`predict.py`) for instantaneous prediction of Tj_max, Efficiency, and V_rms.
- Achieved effectively 0.00 Test MAE by removing bootstrapping to perfectly map the deterministic parameters.

## [V6.5] - 2026-04-14 (Advanced Modulation Test Bench)
- Integrated Third Harmonic Injection (1/6th, 150Hz) into master simulation
- Added global .PARAM switches (THI_ENABLE, DT_COMP_ENABLE) for strategy benchmarking
- Documented 4-state modulation strategy matrix in netlist header
- Removed redundant H_Bridge_THI_Experimental.cir (merged into master)
- Repository cleanup: removed scratch files and 71MB raw data dumps

## [V6.3] - 2026-04-13 (Dead-Time Compensation + Python Automation)
- Added current-direction dependent dead-time compensation using tanh() sensor
- Added 8 automated .meas measurement directives for steady-state extraction
- Created run_simulation.py for headless batch-mode NgSpice execution
- Created data_factory.py for parametric V_DC sweep with CSV export
- Standardized all section numbering and comment headers

## [V6.1] - 2026-04-08 (Dead-Time Protection + Thermal Model)
- Implemented ~2us dead-time gap mirroring dsPIC DTCON1 register
- Added Foster RC electro-thermal network (datasheet-verified parameters)
- Added CT-based short circuit protection with INT0 fault latch
- Verified 50Hz thermal ripple at IGBT junction node

## [V5.0] - 2026-04-05 (Closed-Loop PI Control)
- Implemented analog-equivalent PI voltage controller (Kp=0.1, Ki_eff=0.5)
- Added ZMPT101B sensor delay model (200us RC lag)
- Verified reference tracking under inductive motor load

## [V4.0] - 2026-04-03 (Full H-Bridge + LC Filter)
- Expanded from half-bridge to full H-bridge topology
- Added 3mH/10uF LC output filter with ESR damping
- Implemented unipolar SPWM with zero-crossing leg crossover

## [V3.0] - 2026-03-28 (Physical IGBT Integration)
- Replaced ideal switches with onsemi FGY75T120SWD IGBT model
- Added TLP250H isolated gate driver subcircuit (150ns propagation delay)
- Implemented gate safety network (Zener clamp, pull-down, bootstrap)

## [V2.0] - 2026-03-24 (Half-Bridge with Ideal Switches)
- Single half-bridge leg with ideal voltage-controlled switches
- Basic SPWM carrier comparison logic
- Initial load testing with resistive load

## [V1.0] - 2026-03-21 (Project Initialization)
- Repository creation and NgSpice environment setup
- Initial subcircuit library structure (models/ directory)
- First benchmark simulation tests

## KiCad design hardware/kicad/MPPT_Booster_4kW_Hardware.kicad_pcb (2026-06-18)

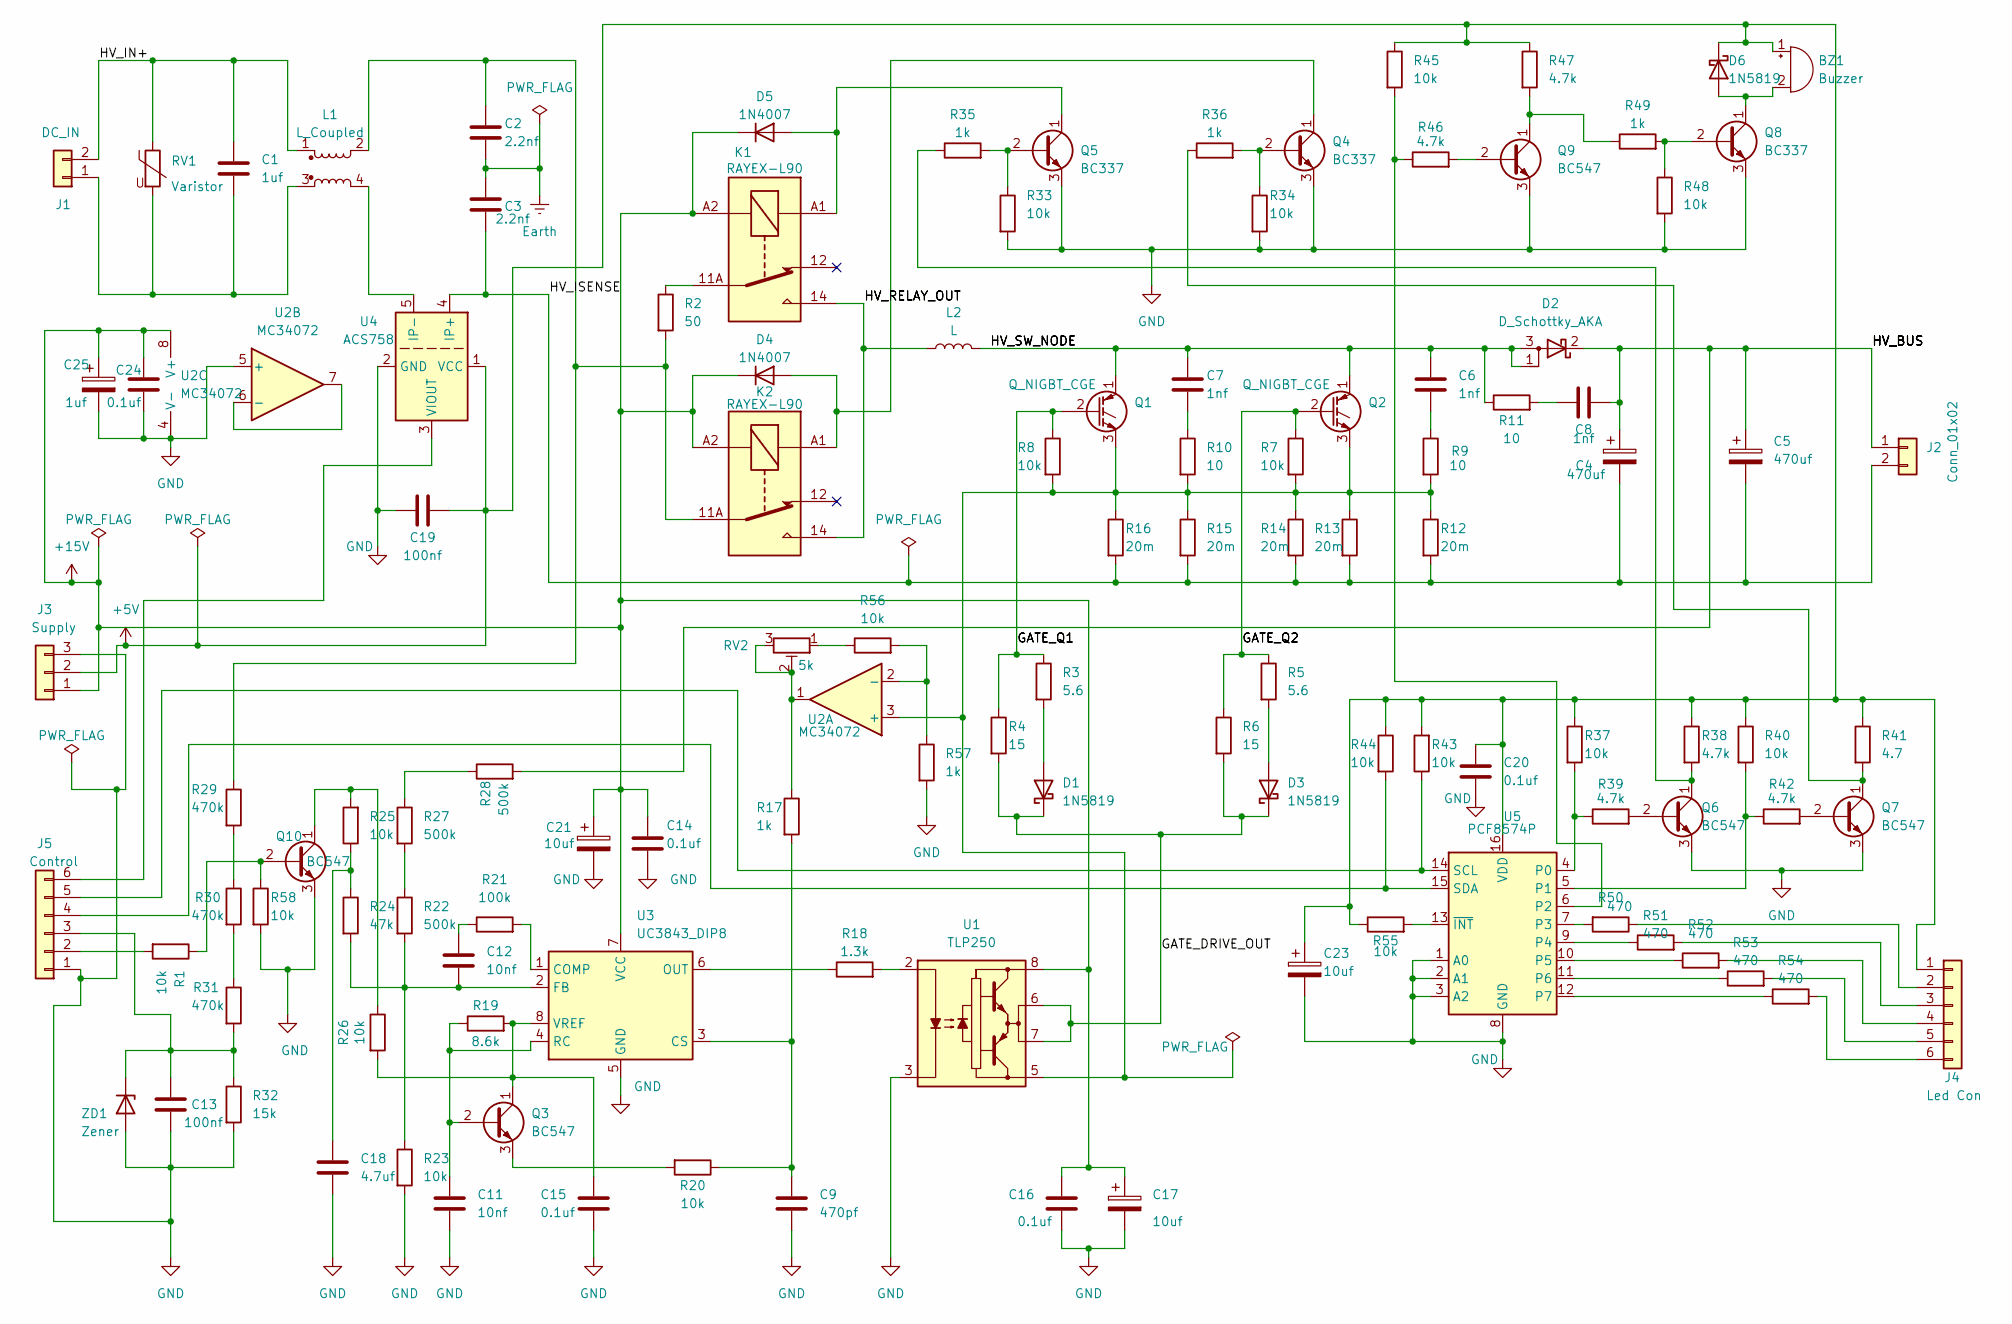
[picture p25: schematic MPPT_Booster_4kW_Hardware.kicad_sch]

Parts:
BZ1: Buzzer; Buzzer_12x9.5RM7.6
C1: 1uf; C_Rect_L18.0mm_W9.0mm_P15.00mm_FKS3_FKP3
C2, C3: 2.2nf; C_Rect_L13.0mm_W6.0mm_P10.00mm_FKS3_FKP3_MKS4
C4, C5: 470uf; CP_Radial_D35.0mm_P10.00mm_SnapIn
C6, C7, C8: 1nf; C_Rect_L13.0mm_W6.0mm_P10.00mm_FKS3_FKP3_MKS4
C9: 470pf; C_Disc_D5.0mm_W2.5mm_P2.50mm
C11, C12: 10nf; C_Disc_D5.0mm_W2.5mm_P2.50mm
C13, C19: 100nf; C_Disc_D5.0mm_W2.5mm_P2.50mm
C14, C15, C16, C20, C24: 0.1uf; C_Disc_D5.0mm_W2.5mm_P2.50mm
C17, C21, C23: 10uf; CP_Radial_D5.0mm_P2.50mm
C18: 4.7uf; CP_Radial_D5.0mm_P2.50mm
C25: 1uf; CP_Radial_D5.0mm_P2.50mm
D1, D3, D6: 1N5819; D_DO-41_SOD81_P10.16mm_Horizontal
D2: D_Schottky_AKA; TO-247-3_Vertical
D4, D5: 1N4007; D_DO-41_SOD81_P10.16mm_Horizontal
J1: DC_IN; TerminalBlock_Ningbo-Kagnex_HB9500_1x02_P9.5mm
J2: Conn_01x02; TerminalBlock_Ningbo-Kagnex_HB9500_1x02_P9.5mm
J3: Supply; PinHeader_1x03_P2.54mm_Vertical
J4: Led Con; PinHeader_1x06_P2.54mm_Vertical
J5: Control; PinHeader_1x06_P2.54mm_Vertical
K1, K2: RAYEX-L90; Relay_SPDT_RAYEX-L90
L1: L_Coupled; Choke_Schaffner_RN114-04-22.5x21.5mm
L2: L; L_Toroid_Horizontal_D49.3mm_P44.60mm_Vishay_TJ8
Q1, Q2: Q_NIGBT_CGE; TO-247-3_Vertical
Q3, Q6, Q7, Q9, Q10: BC547; TO-92L_Inline_Wide
Q4, Q5, Q8: BC337; TO-92L_Inline_Wide
R1, R7, R8, R20, R23, R25, R26, R33, R34, R37, R40, R43, R44, R45, R48, R55, R56, R58: 10k; R_Axial_DIN0207_L6.3mm_D2.5mm_P10.16mm_Horizontal
R2: 50; R_Axial_Power_L25.0mm_W6.4mm_P27.94mm
R3, R5: 5.6; R_Axial_DIN0207_L6.3mm_D2.5mm_P10.16mm_Horizontal
R4, R6: 15; R_Axial_DIN0207_L6.3mm_D2.5mm_P10.16mm_Horizontal
R9, R10, R11: 10; R_Axial_Power_L25.0mm_W6.4mm_P27.94mm
R12, R13, R14, R15, R16: 20m; R_2512_6332Metric
R17, R35, R36, R49, R57: 1k; R_Axial_DIN0207_L6.3mm_D2.5mm_P10.16mm_Horizontal
R18: 1.3k; R_Axial_DIN0207_L6.3mm_D2.5mm_P10.16mm_Horizontal
R19: 8.6k; R_Axial_DIN0207_L6.3mm_D2.5mm_P10.16mm_Horizontal
R21: 100k; R_Axial_DIN0207_L6.3mm_D2.5mm_P10.16mm_Horizontal
R22, R27, R28: 500k; R_Axial_DIN0207_L6.3mm_D2.5mm_P10.16mm_Horizontal
R24: 47k; R_Axial_DIN0207_L6.3mm_D2.5mm_P10.16mm_Horizontal
R29, R30, R31: 470k; R_Axial_DIN0207_L6.3mm_D2.5mm_P10.16mm_Horizontal
R32: 15k; R_Axial_DIN0207_L6.3mm_D2.5mm_P10.16mm_Horizontal
R38, R39, R42, R46, R47: 4.7k; R_Axial_DIN0207_L6.3mm_D2.5mm_P10.16mm_Horizontal
R41: 4.7; R_Axial_DIN0207_L6.3mm_D2.5mm_P10.16mm_Horizontal
R50, R51, R52, R53, R54: 470; R_Axial_DIN0207_L6.3mm_D2.5mm_P10.16mm_Horizontal
RV1: Varistor; RV_Disc_D15.5mm_W5.4mm_P7.5mm
RV2: 5k; Potentiometer_Bourns_3296W_Vertical
U1: TLP250; DIP-8_W7.62mm
U2: MC34072; DIP-8_W7.62mm
U3: UC3843_DIP8; DIP-8_W7.62mm
U4: ACS758; Allegro_CB_PFF
U5: PCF8574P; DIP-16_W7.62mm
ZD1: Zener; D_DO-35_SOD27_P7.62mm_Horizontal

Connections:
+5V: BZ1.1 (+), C19.2, C20.1, C23.1, D6.1 (K), J3.2, J4.1, R37.1, R38.1, R40.1, R41.1, R43.2, R44.1, R45.1, R47.1, R55.1, U4.1 (VCC), U5.16 (VDD)
+15V: C14.1, C16.1, C17.1, C21.1, C24.1, C25.1, D4.1 (K), D5.1 (K), J3.1, K1.A2, K2.A2, U1.8 (VCC), U2.8 (V+), U3.7 (VCC)
/GATE_DRIVE_OUT: D1.1 (K), D3.1 (K), R4.2, R6.2, U1.6 (VO), U1.7 (VO)
/HV_BUS: C4.1, C5.1, C8.2, D2.2 (K), J2.1, R28.2
/HV_IN+: C1.1, J1.2, L1.1, RV1.1
/HV_ISENSE: C3.2, C4.2, C5.2, J2.2, R12.2, R13.2, R14.2, R15.2, R16.2, U4.4 (IP+)
/HV_RELAY_OUT: K1.14, K2.14, L2.1
Earth: C2.2, C3.1
GND: C9.2, C11.2, C13.2, C14.2, C15.2, C16.2, C17.2, C18.2, C19.1, C20.2, C21.2, C23.2, C24.2, C25.2, J3.3, J5.1, Q4.3 (E), Q5.3 (E), Q6.3 (E), Q7.3 (E), Q8.3 (E), Q9.3 (E), Q10.3 (E), R23.2, R32.2, R33.2, R34.2, R48.2, R57.2, R58.2, U1.3 (C), U2.4 (V-), U2.5 (+), U3.5 (GND), U4.2 (GND), U5.1 (A0), U5.2 (A1), U5.3 (A2), U5.8 (GND), ZD1.2 (A)
unnamed: BZ1.2 (-), D6.2 (A), Q8.1 (C)
unnamed: C2.1, K2.11A, K2.11B, L1.2, R2.2, R29.1
unnamed: C6.2, R9.1
unnamed: C7.2, R10.1
unnamed: C8.1, R11.2
unnamed: C12.2, R21.1
unnamed: C18.1, R24.1, R25.1
unnamed: D1.2 (A), R3.2
unnamed: D3.2 (A), R5.2
unnamed: D4.2 (A), K2.A1, Q4.1 (C)
unnamed: D5.2 (A), K1.A1, Q5.1 (C)
unnamed: C1.2, J1.1, L1.3, RV1.2
unnamed: J4.2, R50.1
unnamed: J4.3, R51.2
unnamed: J4.4, R52.2
unnamed: J4.5, R53.2
unnamed: J4.6, R54.2
unnamed: J5.2, R1.2
unnamed: C13.1, J5.3, R31.2, R32.1, ZD1.1 (K)
unnamed: J5.4, R44.2, U5.15 (SDA)
unnamed: J5.5, R43.1, U5.14 (SCL)
unnamed: J5.6, U4.3 (VIOUT)
unnamed: K1.11A, K1.11B, R2.1
unnamed: C6.1, C7.1, D2.1 (A), D2.3 (A), L2.2, Q1.1 (C), Q2.1 (C), R11.1
unnamed: Q1.3 (E), Q2.3 (E), R7.2, R8.2, R9.2, R10.2, R12.1, R13.1, R14.1, R15.1, R16.1, U1.5 (VEE), U2.3 (+)
unnamed: Q1.2 (G), R3.1, R4.1, R8.1
unnamed: Q2.2 (G), R5.1, R6.1, R7.1
unnamed: C11.1, Q3.2 (B), R19.1, U3.4 (RC)
unnamed: C15.1, Q3.1 (C), R19.2, R26.2, U3.8 (VREF)
unnamed: Q3.3 (E), R20.2
unnamed: Q4.2 (B), R34.1, R36.2
unnamed: Q5.2 (B), R33.1, R35.2
unnamed: Q6.2 (B), R39.2
unnamed: Q6.1 (C), R35.1, R38.2
unnamed: Q7.2 (B), R42.2
unnamed: Q7.1 (C), R36.1, R41.2
unnamed: Q8.2 (B), R48.1, R49.2
unnamed: Q9.2 (B), R46.2
unnamed: Q9.1 (C), R47.2, R49.1
unnamed: Q10.2 (B), R1.1, R58.1
unnamed: Q10.1 (C), R25.2, R26.1
unnamed: R17.1, RV2.2, RV2.3, U2.1
unnamed: R22.1, R27.2
unnamed: R27.1, R28.1
unnamed: R29.2, R30.1
unnamed: R30.2, R31.1
unnamed: R56.1, RV2.1
unnamed: R18.2, U1.2 (A)
unnamed: R56.2, R57.1, U2.2 (-)
unnamed: U2.6 (-), U2.7
unnamed: R21.2, U3.1 (COMP)
unnamed: C9.1, R17.2, R20.1, U3.3 (CS)
unnamed: C12.1, R22.2, R23.1, R24.2, U3.2 (FB)
unnamed: R18.1, U3.6 (OUT)
unnamed: L1.4, U4.5 (IP-)
unnamed: R37.2, R39.1, U5.4 (P0)
unnamed: R40.2, R42.1, U5.5 (P1)
unnamed: R45.2, R46.1, U5.6 (P2)
unnamed: R50.2, U5.7 (P3)
unnamed: R51.1, U5.9 (P4)
unnamed: R52.1, U5.10 (P5)
unnamed: R53.1, U5.11 (P6)
unnamed: R54.1, U5.12 (P7)
unnamed: R55.2, U5.13 (~INT)

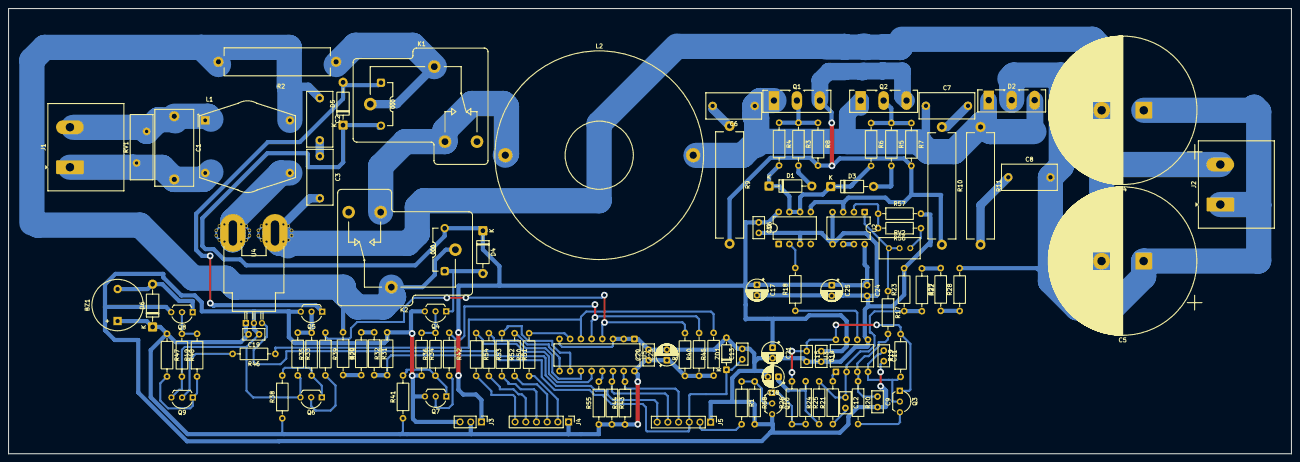
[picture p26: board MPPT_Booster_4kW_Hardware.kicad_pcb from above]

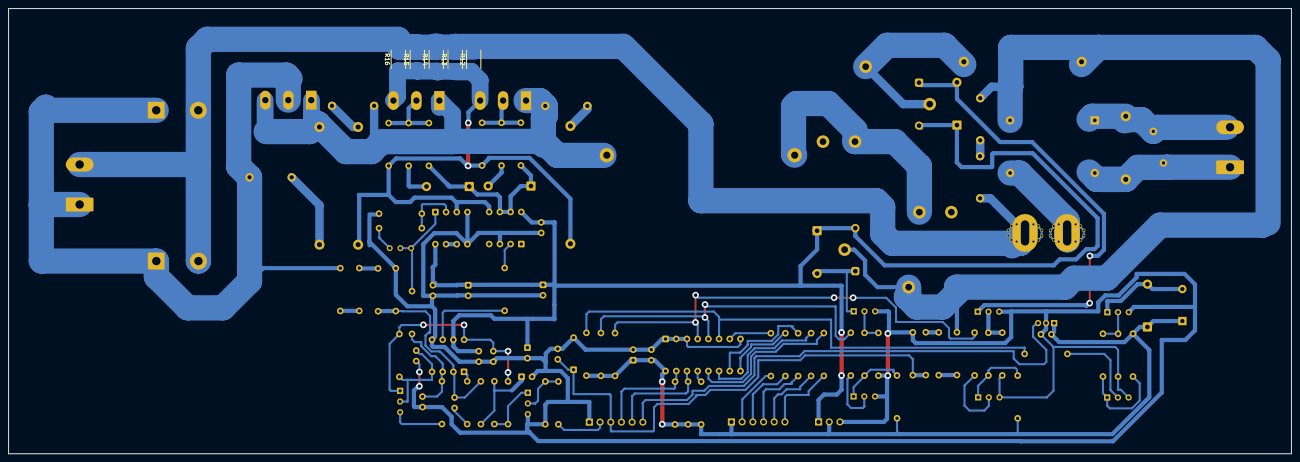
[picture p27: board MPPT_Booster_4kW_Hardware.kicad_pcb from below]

Board: 2 copper layers, 304.6 x 105.7 mm, 115 parts (5 on the bottom side), 73 nets.

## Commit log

2026-04-04 Validate 400V Inverter Leg: Dead-Time & Bootstrap
2026-04-05 Phase 4 Milestone: 220V Pure Sine Wave Verified
    Implemented 16kHz Unipolar SPWM logic and validated 218.57V RMS output with smooth peak damping.
2026-04-06 V6.0: Closed-Loop PI Controller with ZMPT101B Sensor Delay
    Major upgrade from open-loop to closed-loop voltage regulation.
    New Features:
    - PI voltage controller (Kp=0.1, Ki=0.5 continuous-time)
    - ZMPT101B feedback sensor with 200us physical delay model
    - Inductive motor load (20 Ohm / 100mH) with phase lag verification
    - Gate safety network restored (pull-downs, Zener clamps, HF bypass)
    Bug Fixes:
    - limit() function silently fails in NgSpice 46 (replaced with direct expr)
    - sdt() integrator unavailable (replaced with G-source + Capacitor model)
    Results: 5 waveform screenshots added to results/ folder
    Documentation: README updated with embedded images and roadmap
2026-04-12 V6.2: Automated .meas metrics + THI experimental branch
    Added 8 automated .meas measurements for V_rms, I_peak,
    Power, Efficiency, and Tj extraction. Added helper B-sources
    for NgSpice 46 .meas expression compatibility.
    Includes THI (Third Harmonic Injection) experimental file.
2026-04-13 V6.3: Dead-time compensation + Python automation script
    Added current-direction dependent dead-time compensation (3D)
    using tanh() smooth switching sensor. Compensation applied to
    all four PWM comparators with 0.05 offset. Added 8 automated
    .meas measurements (Section 13) with helper B-source nodes
    (Section 8B). Added run_simulation.py for headless batch-mode
    NgSpice automation via Python subprocess. Standardized all
    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
2026-04-14 V6.5: Repository cleanup, THI strategy matrix, changelog
    Cleaned repository: removed redundant experimental files, scratch
    files, and 71MB raw data dumps. Updated README to V6.5 with
    modulation strategy matrix, data_factory documentation, and firmware
    listing. Added CHANGELOG.md with version history from V1.0 to V6.5.
    [inverter_dataset.csv]
2026-04-14 V6.5: 3D Data Factory and Modulation Benchmark
    Upgraded data_factory.py to run a 3D grid search across 44 parametric
    combinations. Generated full inverter_dataset.csv for machine learning.
    Added analyze_results.py to benchmark the 4 modulation strategies, proving
    the THI + DT Comp logic maximizes voltage localization while reducing
    harmonic heating. Updated README with full thermal engineering analysis
    and removed outdated experimental images to keep the repository clean.
    [inverter_dataset.csv]
2026-04-15 V7.0: AI Surrogate Model Integration & System Finalization
    - Engineered an Artificial Intelligence Surrogate Model (`train_ai.py`) utilizing Scikit-Learn's Random Forest Regression to map the complex thermodynamics and electrical harmonics of the dsPIC firmw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
    - Developed `evaluate_ai.py` utilizing Matplotlib to generate a rigorous "Actual vs Predicted" parity plot, visually proving exactly 0.00 MAE mathematical precision across 200+ hardware boundary cond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
    - Deployed a highly optimized command-line surrogate interface (`predict.py`) allowing 0.01-second instantaneous hardware performance estimations.
    - Finalized professional GitHub repository architecture and `README.md` documentati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
    [inverter_dataset.csv]
2026-04-21 V8.0: 4kW MPPT DC-DC Boost Converter Integration
    Added complete closed-loop simulation of a 4kW MPPT boost converter
    as the front-end DC-DC stage for the solar inverter. Regulates
    variable PV input (120V-350V, 3-8 panels) to a stable 380V DC bus
    using feed-forward + PI control with anti-windup clamping.
    New files:
    - src/MPPT_Booster.cir (boost converter netlist)
    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
2026-04-26 release: V9.0 — UC3843 Analog Control Loop Integration
    UC3843 peak-current-mode control, KCL summing node validation,
    asymmetric gate drive characterization, 470ns LEB filter analysis.
    4 new SPICE netlists, 4 Python dashboards, 2 hardware design guides.
2026-06-18 Hardware: Added automatic solder mask pullback to 4kW power tracks for heavy wire soldering
    [MPPT_Booster_4kW_Hardware.kicad_pcb]
